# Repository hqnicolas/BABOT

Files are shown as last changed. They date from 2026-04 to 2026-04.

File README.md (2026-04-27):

# BaBot: Advanced 3-DOF Stewart- Gough Ball-Balancing Robot

An autonomous high-precision ball-balancing instrument predicated on a 3-DOF Stewart-Gough parallel kinematic mechanism. Powered by an ESP32-S3 microcontroller, the system integrates custom KiCad PCB hardware, a high-density 16-channel IR sensory array, and an asynchronous WebSocket-driven control interface for real-time telemetry and PID optimization.

This project represents a modern realization of parallel robotics, bridging classical control theory with contemporary high-frequency embedded systems.

https://github.com/user-attachments/assets/6e9986bd-6b06-4d86-9c46-4f5fcbdaf4ec

**License:** [Creative Commons Attribution-NonCommercial 4.0 International](LICENSE)

---

## Quick Start

### Prerequisites

- Arduino IDE with ESP32 board support
- ESP32-S3 development board or compatible target
- Physical BaBot hardware assembled

### Compilation

1. Open `firmware/firmware.ino` in Arduino IDE.
2. Select **ESP32S3 Dev Module** or your specific ESP32-S3 variant.
3. Click **Compile**.

On Windows, the helper script is also available:

```powershell
.\scripts\compile.ps1
```

### First Boot

1. Power on the robot.
2. Wait for the ESP32-S3 Wi-Fi access point.
3. Connect to Wi-Fi network `12345678` using password `12345678`.
4. Open `http://192.168.4.1/`.
5. The live control dashboard loads with telemetry and runtime controls.

---

## Features

- **Precision 3-DOF Stewart Platform** - A high-rigidity parallel kinematic architecture utilizing three independent actuator branches for precise control of posture and stability.
- **Async Web Control Ecosystem** - Low-latency dual-core dashboard featuring real-time state visualization, ball trajectory overlays, and holistic system diagnostics via WebSockets.
- **High-Density IR Sensory Matrix** - 16-channel infrared detection grid employing signed signal processing and individual multiplexer channel compensation.
- **Synchronized 30Hz Control Loop** - Deterministic real-time control orchestrated by a dedicated FreeRTOS sensor task, ensuring minimal phase lag between optical acquisition and mechanical actuation.
- **Machine Learning PID Autotune** - Autonomous gain discovery utilizing a Multi-Stage CMA-ES (Covariance Matrix Adaptation Evolution Strategy) search algorithm for noise-tolerant feedback optimization.
- **Mathematical Kinematics Solver** - Native C++ real-time implementation of Stewart-Gough inverse kinematics, eliminating the need for legacy lookup tables or offline pre-computation.
- **Robust Fail-Safe Architecture** - Multi-stage subsystem health monitoring with automated recovery protocols and persistent NVS calibration storage.

---

## Firmware Modules

| Module | Purpose |
|---|---|
| `firmware.ino` | Arduino `setup()`/`loop()` orchestration, hardware object composition, and shared runtime state |
| `ButtonInput.h` | Boot-button press decoding and lightweight status LED stubs |
| `ControlLoop.h` | PID, capture impulse, motion grace, telemetry publication, and closed-loop reset helpers |
| `PidAutotune.h` | Safe relay PID autotune state machine, metrics, gain estimation, start/cancel/restore |
| `StartupManager.h` | Bench-safe startup, subsystem health, degraded-mode policy, and deferred hardware bring-up |
| `ModeHandlers.h` | ON/OFF/test/calibration/assembly/position-test mode behavior |
| `UiCommandHandler.h` | Web UI command dispatch, runtime patching, persistence commands, and MUX compensation |
| `BoardConfig.h` | Pin definitions, mux layout, timing, PID defaults, and firmware constants |
| `RuntimeState` | Shared telemetry/config state, UI command queue, status models, and NVS runtime persistence |
| `PlatformControl` | Stewart-platform inverse kinematics and servo commands |
| `IRSensorArray` | Single-mux IR reading, signed signal processing, MUX compensation, ball detection, and centroid calculation |
| `X9C104Digipot` | Digital potentiometer control for IR LED brightness tuning |
| `WebUiServer` | HTTP server, WebSocket telemetry, embedded Web UI, and UI command parsing |
| `DebugLogger` | Async serial logging queue flushed from the Wi-Fi task |

---

## Hardware Pinout

ESP32-S3 control pins are defined in `firmware/src/BoardConfig.h`.

| Signal | GPIO | Notes |
|---|---:|---|
| `SERVO_A` | 41 | Servo output A |
| `SERVO_B` | 2 | Servo output B |
| `SERVO_C` | 1 | Servo output C |
| `IR_LED_CONTROL` | 45 | IR illumination control |
| `BOOT_BUTTON` | 0 | Runtime app button, active-low |
| `U12_CS` | 14 | X9C104 chip select |
| `U12_INCREMENT` | 12 | X9C104 increment |
| `U12_UP/DOWN` | 13 | X9C104 direction |
| `U1_S0` | 40 | CD74HC4067 select line |
| `U1_S1` | 39 | CD74HC4067 select line |
| `U1_S2` | 48 | CD74HC4067 select line |
| `U1_S3` | 47 | CD74HC4067 select line |
| `U1_SIG` | 9 | Multiplexed ADC input |

GPIO 19 and 20 are reserved for ESP32-S3 USB D-/D+.

---

## Operation Modes

### OFF

Platform leveled, no active balancing.

### ON

- No ball detected: platform idles level.
- Fast ball entry or edge approach: capture impulse tilts toward center with normal ON-mode authority up to `20 deg`.
- Ball detected and slowed: velocity-scaled PID keeps the ball centered.
- Recent ball loss: firmware briefly holds the last tilt command, then levels and resets closed-loop state.

### ASSEMBLY

Manual one-servo-at-a-time diagnostic mode for validating mechanical assembly and range of motion.

### CALIBRATION

Interactive servo offset calibration. Offsets are persisted to NVS when calibration completes.

### TEST / INDIVIDUAL_TEST / POSITION_TEST

Open-loop platform diagnostics and synthetic ball-position tests for bring-up. `POSITION_TEST` injects a circular synthetic ball position and runs the normal ON controller, so it exercises the current runtime PID, capture behavior, setpoint, and tilt limits.

---

## Web Dashboard

Once connected to the Wi-Fi AP:

1. **Control Panel** - Tilt visualization, ball position overlay, and mode selector.
2. **Telemetry** - Real-time sensor readings, servo positions, PID state, and system status.
3. **PID Autotune** - Safe relay feedback with measured noise floor, Ku/Pu estimation, capture + PD validation, and small I-value tests.
4. **Configuration and runtime** - Digipot tap, ball threshold, setpoint, PID gains, Save Runtime, Load Runtime, and Reset Defaults.
5. **Tests and calibration** - Servo tests, position tests, assembly/calibration modes, and individual MUX compensation.

All changes sync bidirectionally over WebSocket.

---

## PID Autotune

The **PID Autotune** drawer uses safe relay feedback while actively trying to keep the ball on the tray.

1. It waits for a ball entry inside the safe operating radius.
2. It briefly levels the platform and measures optical/electrical jitter as a noise floor.
3. It runs relay feedback on X and Y with hysteresis greater than the measured noise.
4. It aborts an individual relay attempt if radius, velocity, or detection loss indicate risk, then recovers and waits for a new safe entry.
5. It estimates conservative `Ku`/`Pu`, calculates PD gains, and tests capture + PD.
6. It evaluates only tiny I values: `0.000`, `0.005`, `0.010`, and `0.020`.

Autotune relay tilt is limited to `15 deg`. ON mode can still use the normal `20 deg` platform authority. If relay response remains too noisy or unsafe after repeated safety aborts, autotune fails safely, levels the platform, and restores the previous runtime PID/capture settings. Successful autotune applies values in RAM only; **Save Runtime** remains the only NVS persistence step.

---

## Key Runtime Constants

| Constant | Current value | Notes |
|---|---:|---|
| `kControlIntervalUs` | `33333` | 30 Hz Nominal control periodicity |
| `kProportionalGain` | `3.4` | Optimized legacy proportional gain |
| `kIntegralGain` | `0.06` | Optimized legacy integral gain |
| `kDerivativeGain` | `12.0` | Optimized legacy derivative gain |
| `kPlateHeightMm` | `115.0` | Design vertical height (Nominal) |
| `kMaxPlateTiltDeg` | `15.0` | Symmetrical mechanical safety authority |
| `kBallThreshold` | `30.0` | Signed IR detection floor |

---

## Bring-Up Checklist

- [ ] Compile firmware without errors.
- [ ] Flash to ESP32-S3 via USB.
- [ ] Connect to the `12345678` Wi-Fi AP and open `http://192.168.4.1/`.
- [ ] Confirm subsystems report ready or clear degraded-state messages.
- [ ] Test `ASSEMBLY` and `CALIBRATION` modes before balancing.
- [ ] Run individual MUX compensation after sensor or lighting changes.
- [ ] Tune digipot tap and ball threshold on real hardware.
- [ ] Test ON mode with slow and moderate ball entries.
- [ ] Run PID Autotune with safe ball entries and verify noise floor, relay crossings, Ku/Pu, confidence, and estimated P/D before saving runtime values.

---

## Third-Party Libraries

Vendored libraries live in `firmware/src/third_party/`:

- ArduinoJson - JSON serialization for web communication under `firmware/src/third_party/ArduinoJson/src`
- Servo - ESP32 servo PWM output
- WebSockets - Bidirectional WebSocket communication
- CD74HC4067 - 16-channel multiplexer control

For versions, upstream sources, and licenses, see [docs/third-party-sources.md](docs/third-party-sources.md).

---

## Documentation

| Document | Content |
|---|---|
| Document | Content |
|---|---|
| [docs/kinematics-theory.md](docs/kinematics-theory.md) | **Maturity Thesis**: Stewart-Gough derivation and system geometry |
| [docs/code-reference.md](docs/code-reference.md) | Firmware architecture, CMA-ES Autotune model, and module responsibilities |
| [docs/hardware-guide.md](docs/hardware-guide.md) | Mechanical assembly and PCB asset organization |
| [docs/autotune-tutorial.md](docs/autotune-tutorial.md) | Procedural guide for autonomous PID optimization |

---

## Safety Notes

- The robot starts in `OFF` mode on power-up.
- Always test on a stable, non-slip surface.
- Keep hands clear of linkages while servos are active.
- Do not use PID Autotune on a partially assembled or mechanically loose platform.
- If autotune reports relay response too noisy or unsafe, improve sensing/mechanics before applying gains.

---

## Contact & Support

https://www.ba-bot.com
https://www.ba-bot.com/manual/

#  License
This project is licensed under the Creative Commons Attribution-NonCommercial 4.0 International License.

#  Contact
For inquiries or support, please contact: info@ba-bot.com

---
# BABOT

The open-source ball-balancing robot you build, program, and bring to life.

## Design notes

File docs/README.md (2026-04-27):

# BaBot - 3-DOF Ball-Balancing Robot

BaBot is a ball-balancing robot built on a 3-DOF Stewart platform. This repository targets the ESP32-S3 hardware revision and is arranged so the firmware compiles directly in Arduino IDE by default.

## Arduino IDE Setup

1. Install Arduino IDE and the `esp32:esp32` board platform.
2. Open the sketch folder [`../firmware/`](../firmware/).
3. Open [`../firmware/firmware.ino`](../firmware/firmware.ino).
4. Select the appropriate ESP32-S3 board target.
5. Compile directly in the IDE.

## Optional Arduino CLI

The CLI remains available as a convenience path, but it is no longer the primary workflow.

```powershell
.\scripts\compile.ps1
```

The helper script is the recommended CLI path because it injects the include roots for the integrated third-party source tree.

You can also compile the sketch directly without the helper script if you pass the same flags:

```powershell
arduino-cli compile --fqbn esp32:esp32:esp32s3 --build-property "build.extra_flags=-I<repo>\\firmware\\src -I<repo>\\firmware\\src\\third_party\\ArduinoJson\\src -I<repo>\\firmware\\src\\third_party\\CD74HC4067\\src -I<repo>\\firmware\\src\\third_party\\Servo\\src -I<repo>\\firmware\\src\\third_party\\WebSockets\\src" .\firmware
```

## Firmware Structure

- [`../firmware/firmware.ino`](../firmware/firmware.ino) keeps the Arduino `setup()` and `loop()` entrypoints plus high-level hardware composition.
- [`../firmware/src/`](../firmware/src/) contains project modules for button input, control loop, PID autotune, startup, mode handlers, UI command handling, drivers, and shared runtime state.
- [`../firmware/src/third_party/`](../firmware/src/third_party/) contains vendored third-party Arduino dependencies used by the default sketch build.
- [`../scripts/`](../scripts/) contains optional helper scripts for compile and dependency refresh.
- [`../hardware/`](../hardware/) contains board CAD, fabrication exports, enclosure assets, and hardware reference material.

## Hardware Revision

The default hardware documented in this repository is the newer main-board revision with a single `74HC4067` mux (`U1`) feeding a `4x4` sensor grid with `16` total sensors.

| Signal | GPIO | Notes |
|---|---:|---|
| `SERVO_A` | `41` | Servo output A |
| `SERVO_B` | `2` | Servo output B |
| `SERVO_C` | `1` | Servo output C |
| `U1_S0` | `40` | Remaining mux select line |
| `U1_S1` | `39` | Remaining mux select line |
| `U1_S2` | `48` | Remaining mux select line |
| `U1_S3` | `47` | Remaining mux select line |
| `U1_SIG` | `9` | Remaining mux ADC signal |
| `U12_INCREMENT` | `12` | X9C104 increment |
| `U12_UP/DOWN` | `13` | X9C104 direction |
| `U12_CS` | `14` | X9C104 chip select |
| `IR_LED_CONTROL` | `45` | IR illumination control |

The firmware pin map in [`../firmware/src/BoardConfig.h`](../firmware/src/BoardConfig.h) now matches this single-mux hardware revision.

## Third-Party Sources

- The required third-party Arduino dependencies live under [`../firmware/src/third_party/`](../firmware/src/third_party/).
- To refresh them from Arduino Library Manager, run `.\scripts\vendor-libraries.ps1`.
- Pinned versions, upstream homes, and retained licenses are tracked in [`third-party-sources.md`](third-party-sources.md).

## Runtime Notes

- The active hardware uses a single `U1` mux bank across `16` sensor positions.
- The sensor grid is `1.8x` larger than the legacy board, so the firmware now scales the mirrored legacy centroid output to preserve the old control logic on the new mechanics.
- The Boot button on GPIO0 is used as the runtime app button with `INPUT_PULLUP`. The firmware ignores boot-held state until the button has first been released after startup, so Boot+Reset still remains available for download mode entry.

- The default digital potentiometer tap is `5`, and the ESP32 12-bit `kBallThreshold` baseline is `60.0`. Both are expected to need hardware recalibration.
- The main loop uses fast-path button handling, a 30 Hz control path, signed IR readings, transient capture impulses for fast ball entries, velocity-scaled PID stabilization, and a persisted servo calibration routine.
- The Web UI **PID Autotune** routine uses safe relay feedback with capture active. It measures the noise floor, uses hysteresis to reject optical/electrical jitter, estimates conservative Ku/Pu-based PD gains, and tests small I values only after capture/PD succeeds.
- The firmware starts a Wi-Fi access point with SSID `12345678` and password `12345678`, serves a live web control page over HTTP, and streams telemetry through WebSocket from a task pinned to core `0`.
- Debug output uses the regular ESP32 serial monitor path. Log records are queued from the control path and flushed from the Wi-Fi/web task so serial printing does not run inline in `loop()`.
- Startup is now split into a safe boot plus deferred hardware stages. The board brings up serial, shared state, Wi-Fi, and the web page first, then initializes actuator, digipot, and IR subsystems one at a time.
- If the previous boot reset during actuator or digipot startup, the next boot automatically skips that risky stage, enables a dummy backend where needed, and reports the degraded state on both serial and the web page instead of looping on reset.

## Web UI Access

1. Power the robot and wait for the ESP32-S3 access point to start.
2. Join the Wi-Fi network named `12345678` using password `12345678`.
3. Open a browser and go to `http://192.168.4.1/`.
4. If `192.168.4.1` does not load, check the connected network details on your phone or computer and use the access point gateway/router IP shown there.
5. Once the page loads, the browser connects back to the robot over WebSocket on port `81` automatically.
6. Check the startup banner and subsystem list at the top of the control panel. On a bench boot with missing hardware, the page should still load and explicitly report any dummy or degraded subsystems.

## Bring-Up Checklist

- Compile in Arduino IDE, or with `arduino-cli compile --fqbn esp32:esp32:esp32s3 .\firmware` plus the project include flags shown above.
- Confirm the remaining `U1` mux bank returns distinct ADC values across all `16` sensor positions.
- Verify the X9C104 only moves when the target tap changes.
- Check neutral platform height, assembly mode, calibration mode, and servo limits.
- Connect to the `12345678` AP, open the hosted page, and verify live ball graphics plus bidirectional variable updates.
- On a bench test with no servos attached, confirm the page still loads, serial logs continue, and the actuator subsystem reports degraded or disabled state instead of rebooting the board.
- Re-tune the digipot default tap and ball threshold on real hardware.

## Reference Documents

- [`code-reference.md`](code-reference.md) - firmware reference for the modular ESP32-S3 codebase
- [`reference/how-it-works.pdf`](reference/how-it-works.pdf) - system theory
- [`reference/manual.pdf`](reference/manual.pdf) - assembly and usage manual
- [`hardware-guide.md`](hardware-guide.md) - hardware asset map for boards, fabrication, and enclosure files

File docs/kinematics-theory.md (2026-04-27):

# BaBot - Kinematics Theory and System Geometry

## 1. Introduction to the Stewart mechanism
The BaBot platform utilizes a 3-DOF (Degrees of Freedom) parallel manipulator based on the Stewart-Gough platform principle. This architecture provides high mechanical rigidity and precise control over the platform's posture, specifically its height ($Z$), roll ($\alpha$), and pitch ($\beta$).

Unlike serial manipulators where errors accumulate along the linkage chain, the parallel arrangement of the BaBot distributes the load and precision across three independent actuator branches (Servos A, B, and C).

## 2. Geometric Constants
The system is defined by five critical physical lengths, as extracted from the legacy robot design:

| Constant | Symbol | Value | Description |
|---|---|---|---|
| `kBaseRadiusMm` | $L$ | $85.0$ mm | Radial distance from the origin to each servo anchor point. |
| `kPlatformRadiusMm` | $R_p$ | $103.92$ mm | Radial distance from the platform center to each linkage anchor. |
| `kServoArmLengthMm` | $r$ | $70.0$ mm | Length of the primary servo horn arm. |
| `kPassiveLinkLengthMm` | $l$ | $85.0$ mm | Length of the passive linkage rod. |
| `kPlateHeightMm` | $d$ | $115.0$ mm | Nominal vertical height of the platform center at rest. |

## 3. Inverse Kinematics (IK)
The Inverse Kinematics problem for the BaBot is: *Given a desired platform height $Z$ and tilt angles $\alpha$ (roll) and $\beta$ (pitch), calculate the required angles $\theta_i$ for each servo motor.*

### 3.1. Reference Frame and Coordinate Mapping
The origin $(0,0,0)$ is located at the geometric center of the base triangle. The three servo anchors are distributed at $120^\circ$ intervals:
- **Servo A**: $210^\circ$ (or $-150^\circ$)
- **Servo B**: $90^\circ$
- **Servo C**: $-30^\circ$ (or $330^\circ$)

### 3.2. Platform Anchor Positions
For a given roll ($\alpha$) and pitch ($\beta$), we define a rotation matrix or use vector rotation to find the position of the three anchor points on the moving plate. The firmware uses a simplified geometric projection since the BaBot typically operates at small tilt angles ($<20^\circ$), but it maintains precision by calculating the absolute 3D position of each anchor relative to its respective base servo anchor.

### 3.3. The Individual Actuator Equation
For each leg, the distance between the servo rotation axis and the platform anchor must be bridged by the combination of the servo arm ($r$) and the passive link ($l$). 

We solve for the leg distance $d_{leg}$ in the vertical action plane of the servo:
$$d_{leg}^2 = \Delta X^2 + \Delta Y^2 + \Delta Z^2$$

Applying the Law of Cosines to the triangle formed by the servo arm $r$, the link $l$, and the distance $d_{leg}$:
$$\cos(\phi) = \frac{r^2 + d_{leg}^2 - l^2}{2 \cdot r \cdot d_{leg}}$$
The final servo angle $\theta$ is then derived from the combination of the geometric elevation of the leg and the internal angle $\phi$:
$$\theta = \text{atan2}(\Delta Z, \Delta X_{planar}) - \phi$$

The ESP32 processes these equations in real-time, allowing for fluid motion without the need for pre-calculated lookup tables.

## 4. Operational Limits and Clamping
Due to the physical lengths of the rods, there is a maximum theoretical height the platform can reach. For the current hardware dimensions:
- **Horizontal Reach Needed**: $\approx 19$ mm (difference between platform and base radii).
- **Max Theoretical Height**: $\approx 154$ mm (at full vertical extension).
- **Practical Default**: $115$ mm, providing a neutral servo angle of $\approx 34.3^\circ$, optimized for maximum symmetrical tilt authority.

The firmware enforces a software clamp on the tilt angles to prevent the servos from reaching "singularity" points where the linkage could flip or lock.

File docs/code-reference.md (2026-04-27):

# BaBot - Firmware Code Reference

Reference for the modular ESP32-S3 firmware in this repository.

## Control Flow

```mermaid
flowchart TD
    A["setup()"] --> B["Initialize config-dependent peripherals"]
    B --> C["Load servo offsets and home digipot"]
    C --> D{"Startup Ready?"}
    D -->|Yes| E["Start Sensor Task (Core 1)"]
    E --> F["loop() / Control Loop (Core 1)"]
    D -->|No| D
    
    subgraph SensorTask ["FREE RTOS: Sensor Task (Core 1)"]
        ST1["measure() ambient → vTaskDelay(10)"]
        ST2["measure() IR → vTaskDelay(10)"]
        ST3["Signal Semaphore: measurementReady"]
        ST1 --> ST2 --> ST3 --> ST1
    end

    subgraph MainLoop ["Arduino loop() (Core 1)"]
        L1["Button check + Mode switching + drain UI commands"]
        L2{"Semaphore: measurementReady?"}
        L2 -->|No| L1
        L2 -->|Yes| L3["Run PID / Autotune / Position Test"]
        L3 --> L4["PlatformControl.movePlatform()"]
        L4 --> L1
    end

    subgraph WebTask ["FREE RTOS: Web Task (Core 0)"]
        W1["Wi-Fi AP + HTTP Server"]
        W2["WebSocket Telemetry + UI Command Enqueue"]
        W1 <--> W2
    end
```

## Files And Responsibilities

### [`../firmware/firmware.ino`](../firmware/firmware.ino)

- Keeps Arduino `setup()` and `loop()` entrypoints, hardware object composition, and shared runtime state.
- Includes focused internal modules for button input, control loop, PID autotune, startup, mode handlers, and UI command handling.
- Orchestrates the cooperative execution between the Arduino loop and the FreeRTOS sensor measurement task.

### Internal Firmware Modules

- `ButtonInput.h` decodes Boot-button press patterns and owns lightweight status LED stubs.
- `ControlLoop.h` owns PID, capture impulse, motion grace, telemetry publication, and closed-loop reset helpers.
- `PidAutotune.h` owns safe relay PID autotune, metrics, gain estimation, and previous-gain restore.
- `StartupManager.h` owns bench-safe startup, subsystem health, degraded-mode policy, and deferred hardware initialization.
- `ModeHandlers.h` owns ON/OFF/test/calibration/assembly/position-test behavior.
- `UiCommandHandler.h` owns Web UI command dispatch, runtime patching, persistence commands, and MUX compensation.

### [`../firmware/src/BoardConfig.h`](../firmware/src/BoardConfig.h)

- Defines the `BoardPins`, `MuxPins`, and all firmware constants.
- Encodes the routed single-mux pin map, including the `GPIO45` IR LED control line, Boot button, Wi-Fi AP settings, and web-task timing.

### [`../firmware/src/RuntimeState.h`](../firmware/src/RuntimeState.h)

- Defines shared `TelemetryState`, `RuntimeConfig`, and `UiCommand` types.
- Defines the shared `SystemStatus` model used for startup phase, subsystem health, and degraded-mode reporting.
- Publishes PID autotune metrics such as baseline/best scores, candidate queue status, progress, trial counts, and per-stage gain suggestions.
- Owns the FreeRTOS queue used to move browser-originated changes onto the control core.
- Persists runtime tuning values in the `babot_ui` NVS namespace.

### [`../firmware/src/WebUiServer.h`](../firmware/src/WebUiServer.h)

- Starts a task pinned to core `0`.
- Hosts the access-point web page and `/api/state`.
- Broadcasts telemetry/config/system-health snapshots over WebSocket, enqueues parsed commands, and flushes queued serial debug output.
- Hosts the **PID Autotune** drawer and sends start/cancel/restore commands to the control loop.

### [`../firmware/src/DebugLogger.h`](../firmware/src/DebugLogger.h)

- Owns the fixed-size FreeRTOS queue used for non-blocking debug records.
- Lets the control path enqueue bring-up logs without writing directly to the serial monitor.
- Flushes queued logs from the Wi-Fi/web task so serial transport stays off the control loop.

### [`../firmware/src/IRSensorArray.h`](../firmware/src/IRSensorArray.h)

- Samples ambient and IR-lit readings across `16` channels using a dedicated FreeRTOS task.
- Uses `vTaskDelay` during IR LED settling to yield CPU time back to the main loop and network task.
- Signals the control loop via a binary semaphore once a full measurement cycle is complete.
- Applies exponential moving average smoothing to the IR delta.
- Applies persisted per-channel MUX compensation before ball detection and centroid calculation.
- Detects ball presence from `max(irSignal) - min(irSignal) >= kBallThreshold`.
- Preserves signed IR deltas so covered sensors can report below zero instead of being clamped.
- Mirrored-edge centroid calculation over the `4x4` grid so edge sensors behave like the Leonardo firmware.
- Scales the reported `centerX` / `centerY` coordinates by `1.8x` to match the larger physical sensor grid on the new hardware.
- Emits optional CSV telemetry.

### [`../firmware/src/PlatformControl.h`](../firmware/src/PlatformControl.h)

- Wraps the three `Servo` instances.
- Implementation of the Inverse Kinematics (IK) logic. For the underlying mathematical derivation, see [Kinematics Theory](kinematics-theory.md).
- Leg-to-servo ordering (`C`, `A`, `B`) inside `movePlatform()` so closed-loop motion matches the old board.
- Attaches servos with explicit pulse widths for the ESP32 PWM implementation.
- Persists per-servo calibration offsets in ESP32 NVS using `Preferences`.
- Falls back to a dummy backend when startup policy or init results disable real actuator output.

### [`../firmware/src/X9C104Digipot.h`](../firmware/src/X9C104Digipot.h)

- Replaces the previous absolute-byte digipot write path.
- Tracks the last known tap in RAM.
- Homes to zero when first used, then steps incrementally to the requested tap.
- Supports optional non-volatile store via the `persist` argument to `setTap()`.
- Can also run in a dummy mode that preserves the requested tap in software without touching GPIO.

## Startup Model

- `setup()` now performs only safe boot work first: serial, button basics, config load, shared state, and Wi-Fi/web startup.
- Riskier hardware stages then run one at a time from `loop()`: actuator backend, digipot restore, and IR sensor bring-up.
- A tiny NVS startup journal records the currently attempted risky stage. If the board resets during that stage, the next boot skips it and reports the recovery through serial and the web UI.
- `ON` mode can continue with a dummy actuator backend for bench testing, but actuator test modes are blocked unless real servo output is available.

## Key Constants

| Constant | Value | Notes |
|---|---:|---|
| `kProportionalGain` | `3.4` | Default PID proportional gain |
| `kIntegralGain` | `0.06` | Default PID integral gain |
| `kDerivativeGain` | `12.0` | Default PID derivative gain |
| `kServoArmLengthMm` | `70.0` | Primary servo horn arm length |
| `kPassiveLinkLengthMm` | `85.0` | Passive linkage rod length |
| `kBaseRadiusMm` | `85.0` | Radius to base servo mounts |
| `kPlatformRadiusMm` | `103.9` | Radius to platform anchors |
| `kPlateHeightMm` | `115.0` | Neutral resting height |
| `kIrAlpha` | `0.8` | IR delta smoothing |
| `kBallPositionAlpha` | `0.7` | Ball position smoothing |
| `kMaxPlateTiltDeg` | `15.0` | Safety clamp for roll/pitch |
| `kBallThreshold` | `30.0` | IR signal detection threshold |
| `kSensorCount` | `16` | 1 mux x 16 channels |
| `kPositionTestRadius` | `1.2` | Simulated path radius for `POSITION_TEST` |

## Position Test

- `POSITION_TEST` is a controller test, not a sensor-channel sweep.
- It injects a synthetic circular ball position inside the same coordinate limits used by `ON` mode.
- It then calls the normal ON controller path, so the current runtime PID, capture behavior, setpoint, ball threshold, and `kMaxPlateTiltDeg` clamp are exercised together.
- Individual MUX/channel validation belongs to the MUX compensation and sensor diagnostics flow, not `POSITION_TEST`.

## PID Autotune Model

- Autotune utilizes a **Multi-Stage CMA-ES (Covariance Matrix Adaptation Evolution Strategy)** optimizer, a machine learning method designed for noise-tolerant search in high-dimensional feedback loops.
- It operates in three distinct phases:
    1. **Baseline**: Establishes a performance floor using current gains.
    2. **CMA-ES Evolution**: Samples a population of 6 candidates from a dynamic Gaussian distribution. It adaptively learns from each evaluation, shifting the search mean and adjusting the covariance matrix to stretch along the most promising gain directions.
    3. **Tune I**: Fine-tunes the Integral gain once the P/D stabilization is optimized, minimizing steady-state error.
- **Scoring Function**:
    - Each candidate is graded via a composite cost function: `Score = (Avg Radius * 150) + (Avg Speed * 120) + (Peak Speed * 50) + (Time * 0.04)`.
    - **Edge Penalty**: If the ball is "captured" but remains against the outer fence (Avg Radius > 0.8), a 300-point penalty is applied.
- **Robustness**: 
    - **Trial Averaging**: Each candidate is tested over `kPidAutotuneTrialsPerCandidate = 3` trials.
    - **Safety & Early Cancel**: The autotuner allows the full platform tilt (10.0°). If the user cancels the session early, the **best gains found so far** are automatically applied to the active controller.
- Autotune applies the resulting values in RAM only. `Save Runtime` remains the only NVS persistence step.

## Third-Party Layout

- Vendored dependencies live under [`../firmware/src/third_party/`](../firmware/src/third_party/), including ArduinoJson under `ArduinoJson/src`.
- Arduino IDE is the primary workflow. The helper compile script exists for CLI convenience and injects the include roots needed for the vendored source layout.

## Validation Expectations

- The baseline firmware should compile directly with:

```powershell
.\scripts\compile.ps1
```

- The helper script injects the include roots needed by the integrated `src/third_party` source tree:

```powershell
.\scripts\compile.ps1
```

## Hardware Caveats

- `kBallThreshold = 60.0` and `kDefaultDigipotTap = 5` are current bring-up values and still need hardware validation.
- Bench validation is still required for servo limits, sensor orientation, threshold tuning, and digipot calibration.

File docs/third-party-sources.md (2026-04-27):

# Third-Party Sources

This repository vendors the build-relevant portions of its third-party Arduino dependencies under `firmware/src/third_party/`.

| Dependency | Version | Upstream | Retained license files |
|---|---|---|---|
| Servo | current vendored copy | https://github.com/arduino-libraries/Servo | docs/ + examples/ included upstream |
| CD74HC4067 | 1.0.2 | https://github.com/waspinator/CD74HC4067 | LICENSE |
| WebSockets | 2.7.2 | https://github.com/Links2004/arduinoWebSockets | LICENSE |
| Async TCP | 3.3.2 | https://github.com/me-no-dev/asynctcp | LICENSE |
| ESP Async WebServer | 3.6.0 | https://github.com/me-no-dev/espasyncwebserver | LICENSE |
| ArduinoJson | 7.4.3 | https://github.com/bblanchon/ArduinoJson | LICENSE.txt (`firmware/src/third_party/ArduinoJson/src`) |

Refresh with `.\scripts\vendor-libraries.ps1`, then verify with `arduino-cli compile --fqbn esp32:esp32:esp32s3 .\firmware` or `.\scripts\compile.ps1`.

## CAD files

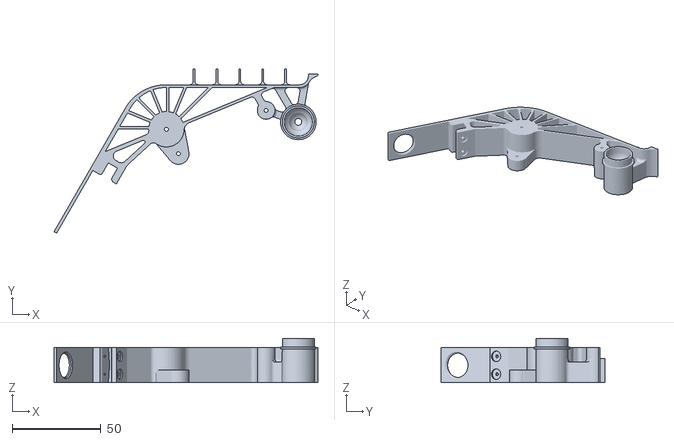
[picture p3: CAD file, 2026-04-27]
hardware/enclosure/interieur3Print1time.stl
148.6 x 92.5 x 25.0

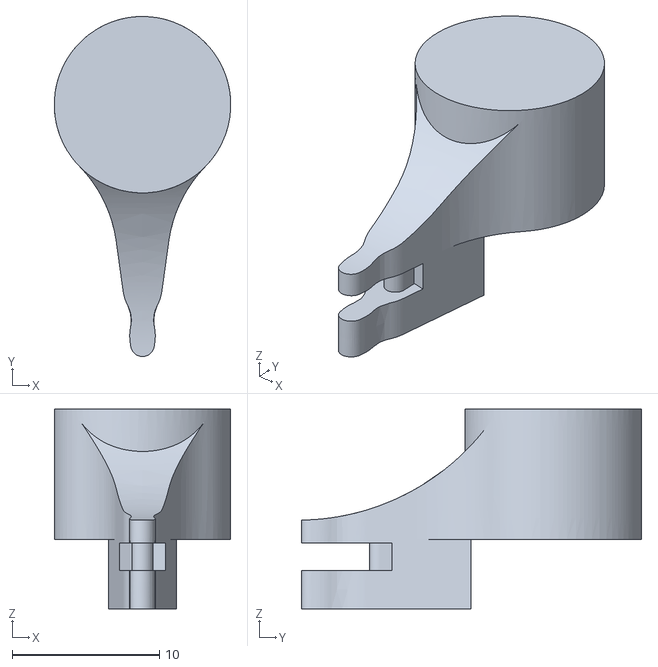
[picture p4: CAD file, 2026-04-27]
hardware/enclosure/3X_holder.stl
12.0 x 23.1 x 13.6

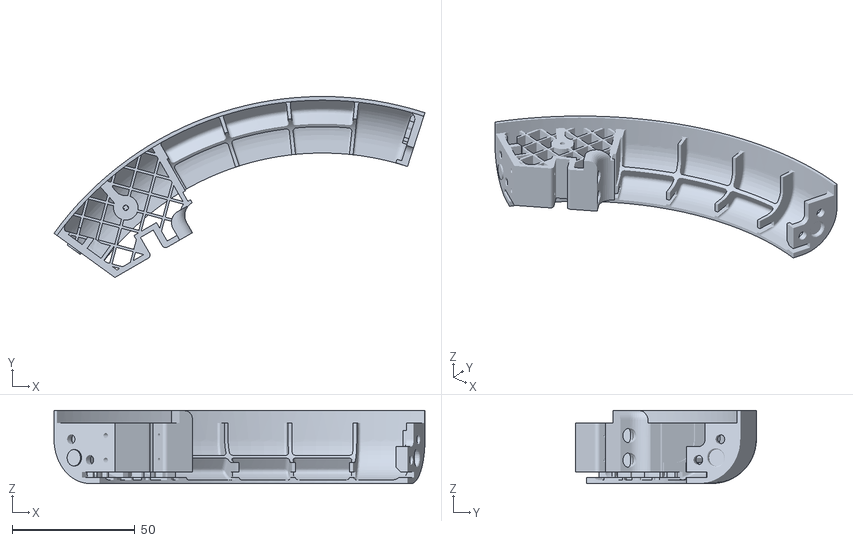
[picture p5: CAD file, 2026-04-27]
hardware/enclosure/contour1Print1time..stl
150.9 x 73.6 x 29.7

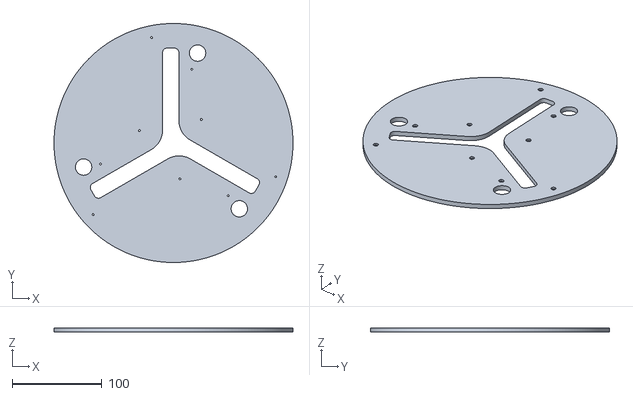
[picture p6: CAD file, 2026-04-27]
hardware/enclosure/superieur.stl
266.9 x 266.9 x 5.00

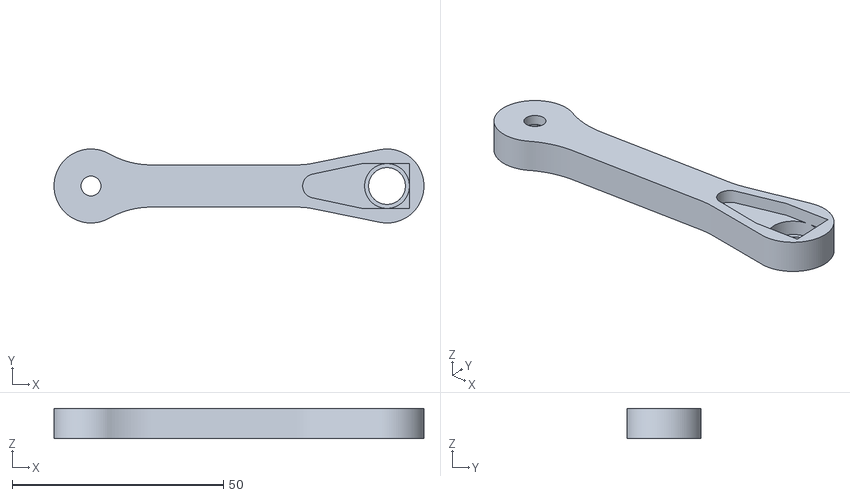
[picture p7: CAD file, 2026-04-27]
hardware/enclosure/arm1print_this_file_3_times.stl
87.5 x 17.5 x 7.20

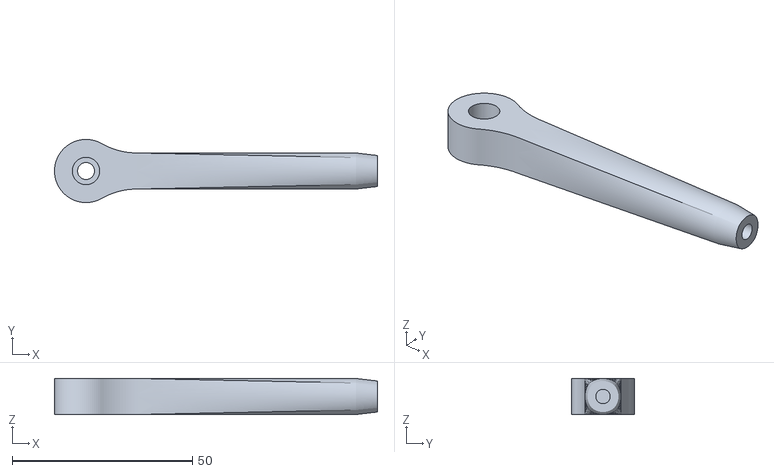
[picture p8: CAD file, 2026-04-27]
hardware/enclosure/arm2print_this_file_3_times.stl
89.5 x 17.5 x 10.0

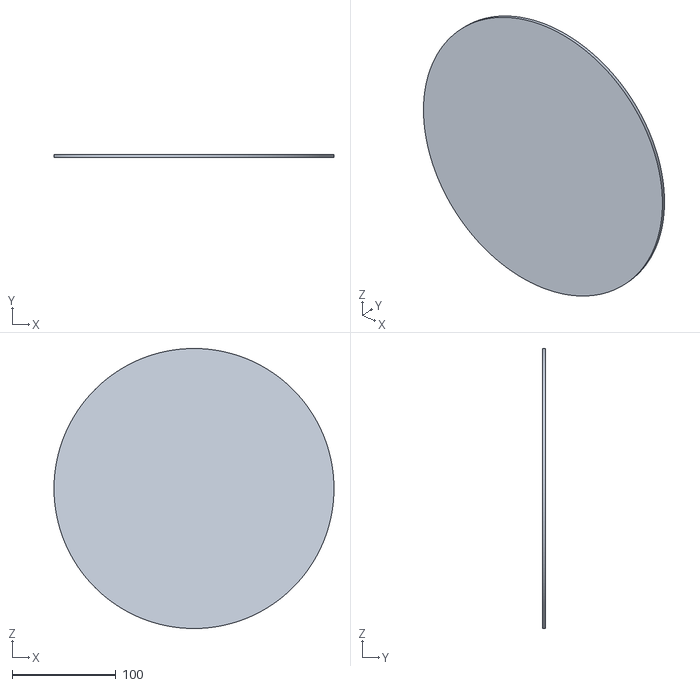
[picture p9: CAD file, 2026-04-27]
hardware/enclosure/plateau.stl
270.0 x 3.00 x 270.0

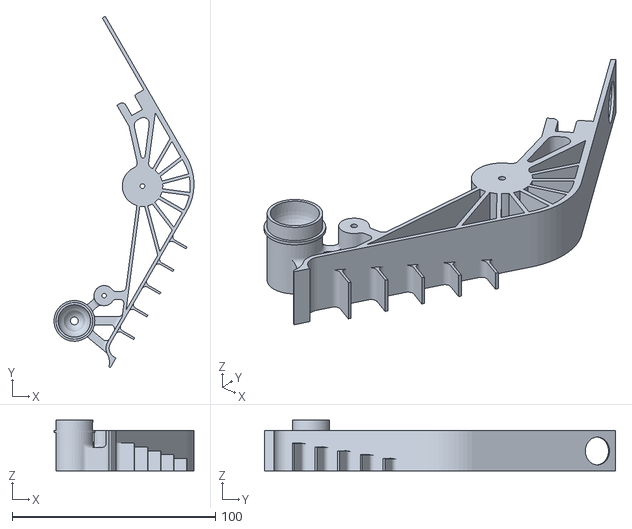
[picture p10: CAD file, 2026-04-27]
hardware/enclosure/interieurPrint1time.stl
68.9 x 173.0 x 25.0

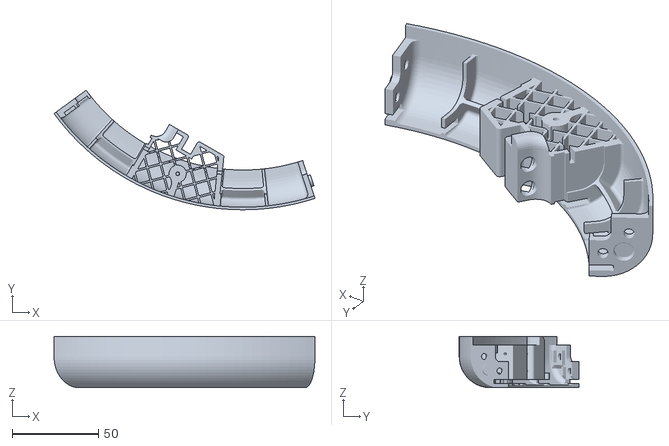
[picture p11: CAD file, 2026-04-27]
hardware/enclosure/contour2Print1time..stl
150.9 x 69.2 x 29.7

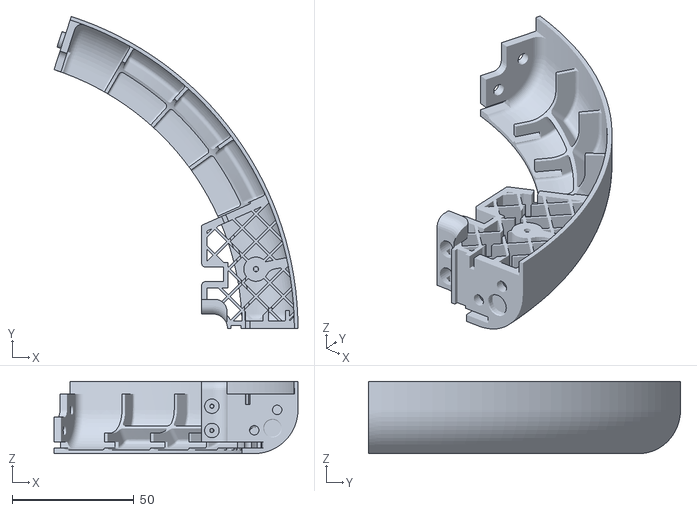
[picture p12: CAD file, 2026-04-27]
hardware/enclosure/contour4Print1time..stl
100.4 x 128.4 x 29.7

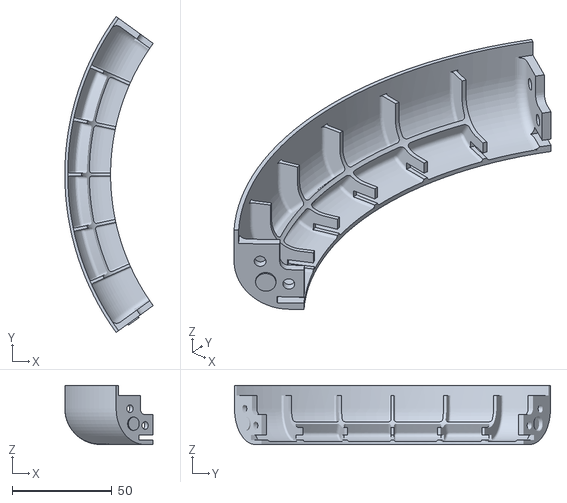
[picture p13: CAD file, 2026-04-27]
hardware/enclosure/contour5Print1time.stl
44.4 x 158.7 x 29.7

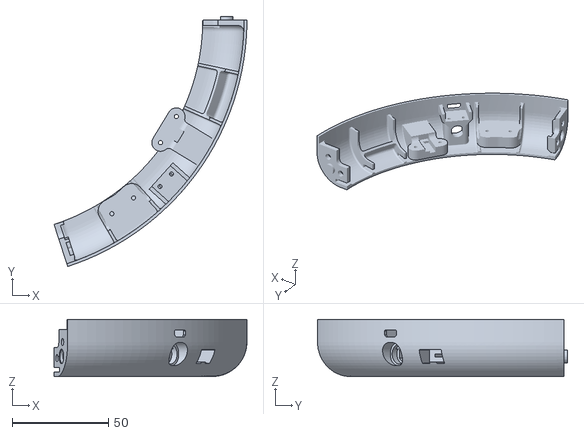
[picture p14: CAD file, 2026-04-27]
hardware/enclosure/contour3Print1time..stl
100.4 x 130.1 x 29.7

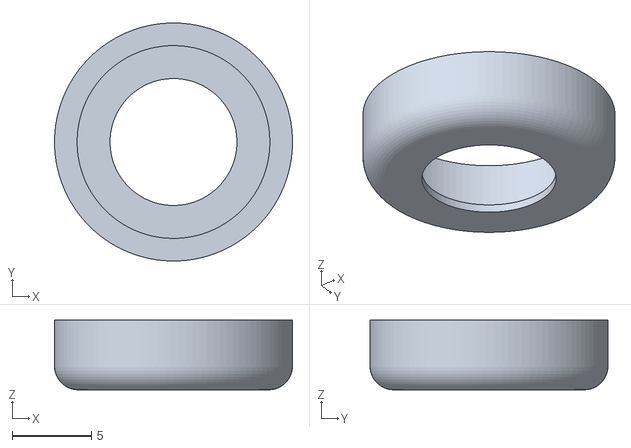
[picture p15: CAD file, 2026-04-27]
hardware/enclosure/print3times.stl
15.0 x 15.0 x 4.39

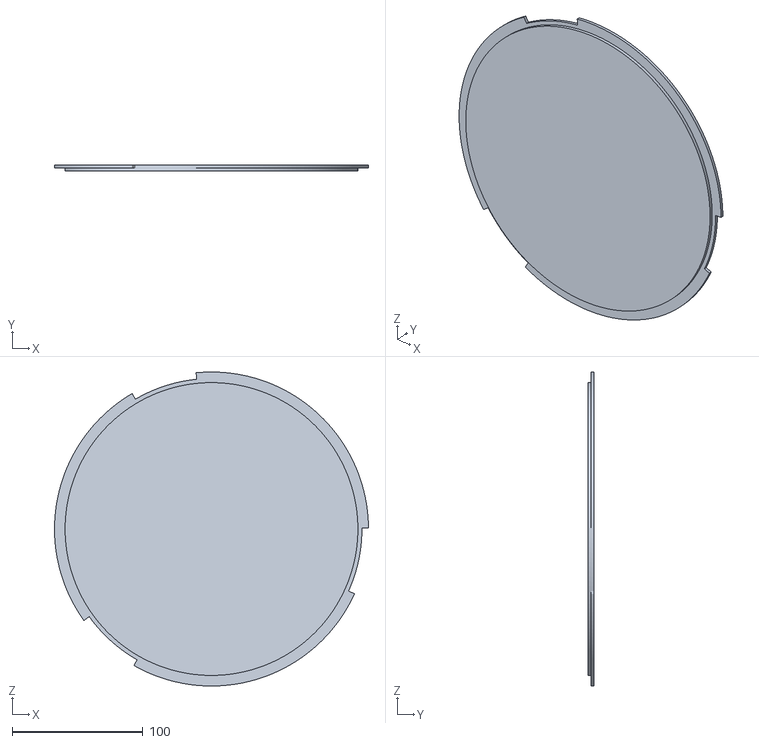
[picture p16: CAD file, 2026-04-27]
hardware/enclosure/inferieur.stl
240.0 x 4.70 x 240.0

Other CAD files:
hardware/enclosure/interieur2Print1time.stl
hardware/enclosure/supportspaced.stl

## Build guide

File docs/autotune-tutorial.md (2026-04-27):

# Tutorial: Testing the BABOT Multi-Stage PID Autotuner

This guide explains how to verify the performance and stability of the BABOT Hill Climbing autotuner.

## Prerequisites
1. **Physical Setup**: Ensure the platform is level and the servos are energized.
2. **Web UI Access**: Navigate to the BABOT Web UI in your browser.
3. **Ball on Standby**: Have the balancing ball ready to place on the plate.

---

## Step 1: Baseline Verification
The autotuner starts by measuring your "current" gains to establish a reference point.

1. Open the **PID Autotune** drawer in the Web UI.
2. Click **Start Autotune**.
3. **Action**: Place the ball on the plate when the status shows "Waiting for ball entry".
4. **Observation**: The system will run 3 trials. After completion, notice the **Baseline Score**. This is your target to beat.

## Step 2: Monitoring the Evolution Phase
The system will now enter **Evolving (CMA-ES)** mode. This is the machine learning phase where BABOT learns the physics of your plate.

1. **Trial Flow**: 
   - The system samples a "population" of 6 candidates per generation.
   - You will see the **Generation** counter (0, 1, 2...).
   - Watch the **Step Size (σ)**. As the system gains confidence in a specific region of PID space, σ will decrease.
2. **Telemetry Check**: 
   - The system automatically shifts its search toward gain combinations that produce lower scores.
   - If a generation fails to find a better set, it will expand its search (increasing σ) to find new stable regions.

## Step 3: Integral Tuning
Once a solid P/D foundation is found, the system switches to **Tuning I**.

1. **Observation**: You will see the status change to "Tuning I".
2. **Logic**: The system is now testing small increments of Integral gain (e.g., 0.005, 0.010).
3. **Criteria**: It looks for the I-gain that reduces steady-state error without making the ball "orbit" the center slowly.

## Step 4: Applying and Saving
1. **Completion**: Once the queue is empty, the status will show **Complete**.
2. **Verification**: The best gains found are automatically applied to the active controller.
3. **Persistence**: If you are happy with the performance, click **Save Runtime** in the Config drawer to write these gains to the ESP32's permanent memory (NVS).

> [!TIP]
> **Don't wait for completion?** If you are satisfied with how the ball is balancing during a trial, you can click **Cancel** at any time. The system will automatically apply the **Best Found Gains** it has recorded so far, allowing you to stop the evolution early once you see a result you like!

---

## Troubleshooting the Test
- **"Waiting for ball entry" persists**: Check your `Ball Threshold` and `Digipot Tap`. The ball must be clearly detected for a trial to start.
- **Tuner stays on one candidate**: Ensure you are not removing the ball too early. The tuner needs 3 consistent trials to move on.
- **Ball pinned against the fence**: If a candidate just pushes the ball to the edge and holds it there, it will be heavily penalized by the **Edge Penalty** (300 points). This ensures the autotuner only considers center-balancing behavior as "Better".
- **Instability**: If the ball is shaking violently, the "Best" gains might be too high for your specific linkage. You can always click **Apply Previous Gains** to revert.

## How to "Stress Test" the Result
After autotuning, switch the mode to **POSITION_TEST**. This will inject a circular synthetic ball position. If the autotune was successful, the plate should follow the simulated circular path smoothly with minimal overshoot.

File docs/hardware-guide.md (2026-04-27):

# Hardware Guide

This repository separates hardware source files, fabrication exports, enclosure assets, and shared KiCad libraries into dedicated folders.

## Hardware Layout

- [`../hardware/boards/main-board/`](../hardware/boards/main-board/) - main-board KiCad source files
- [`../hardware/boards/led-board/`](../hardware/boards/led-board/) - LED-board KiCad source files
- [`../hardware/fabrication/main-board/`](../hardware/fabrication/main-board/) - main-board fabrication and exported reference PDFs
- [`../hardware/fabrication/led-board/`](../hardware/fabrication/led-board/) - LED-board fabrication and exported reference PDFs
- [`../hardware/enclosure/`](../hardware/enclosure/) - 3D-printable enclosure STL files and mechanical reference assets
- [`../hardware/libraries/kicad/`](../hardware/libraries/kicad/) - shared KiCad symbols and footprints
- [`../hardware/reference/tm.pdf`](../hardware/reference/tm.pdf) - additional hardware reference PDF

## Notes

- Board source CAD and fabrication exports are intentionally separated so manufacturing files do not clutter the editable design directories.
- STL filenames are preserved where they appear to be fabrication-ready outputs from the original project.
- The photo asset under `hardware/enclosure/` is kept with the STL files because it documents the printed assembly.

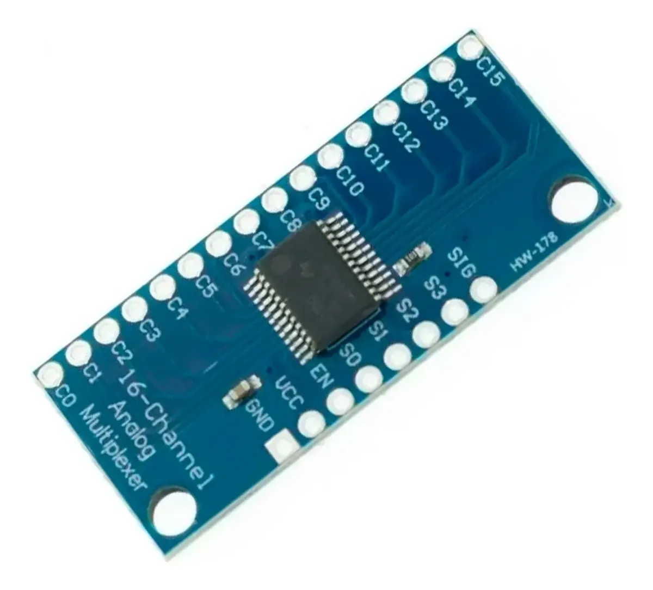
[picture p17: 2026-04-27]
hardware/fabrication/led-board/74HC4067-Board.webp

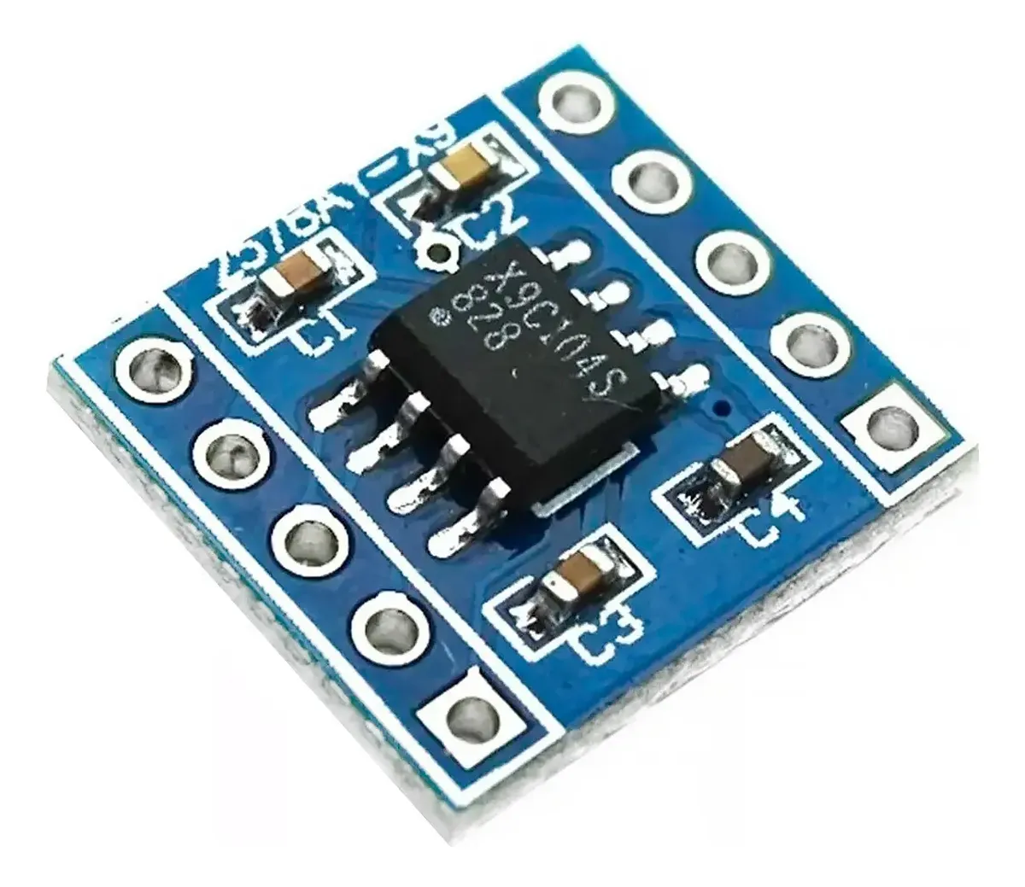
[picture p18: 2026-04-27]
hardware/fabrication/main-board/x9c104-Board.webp

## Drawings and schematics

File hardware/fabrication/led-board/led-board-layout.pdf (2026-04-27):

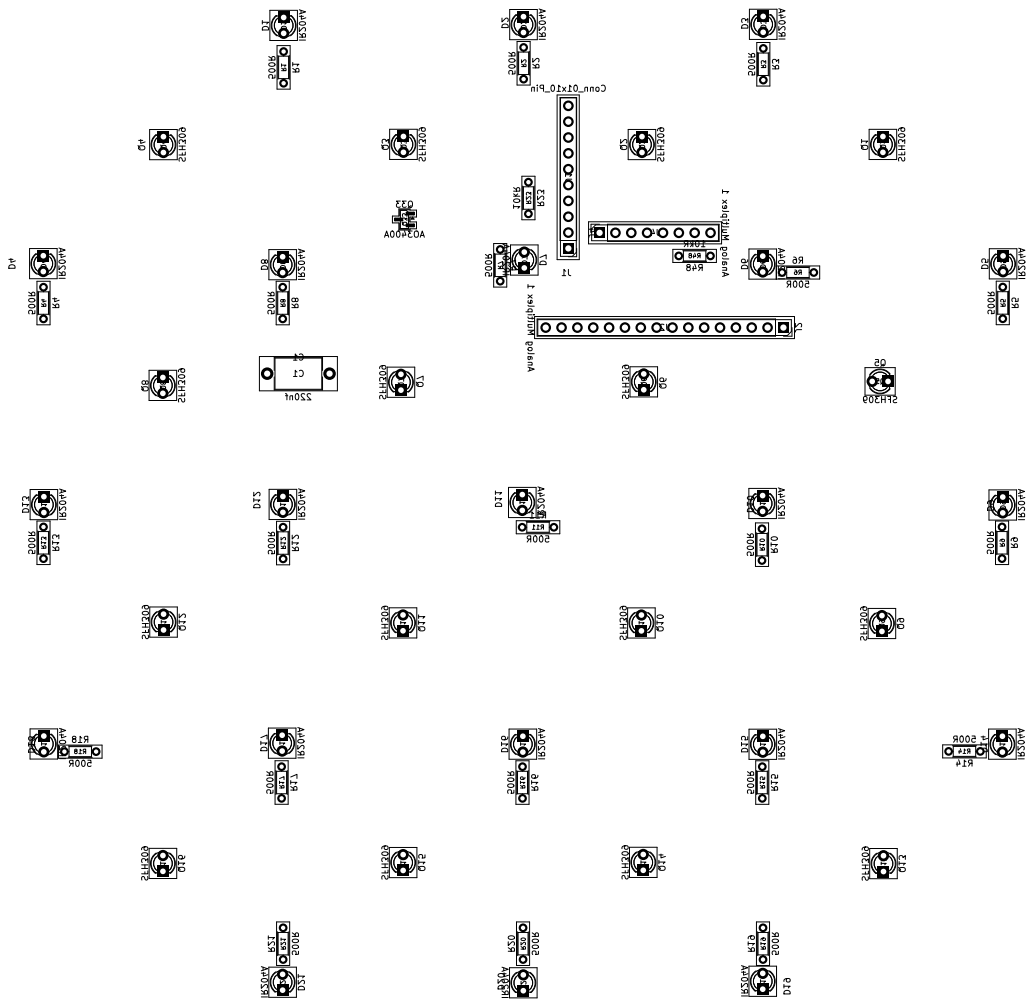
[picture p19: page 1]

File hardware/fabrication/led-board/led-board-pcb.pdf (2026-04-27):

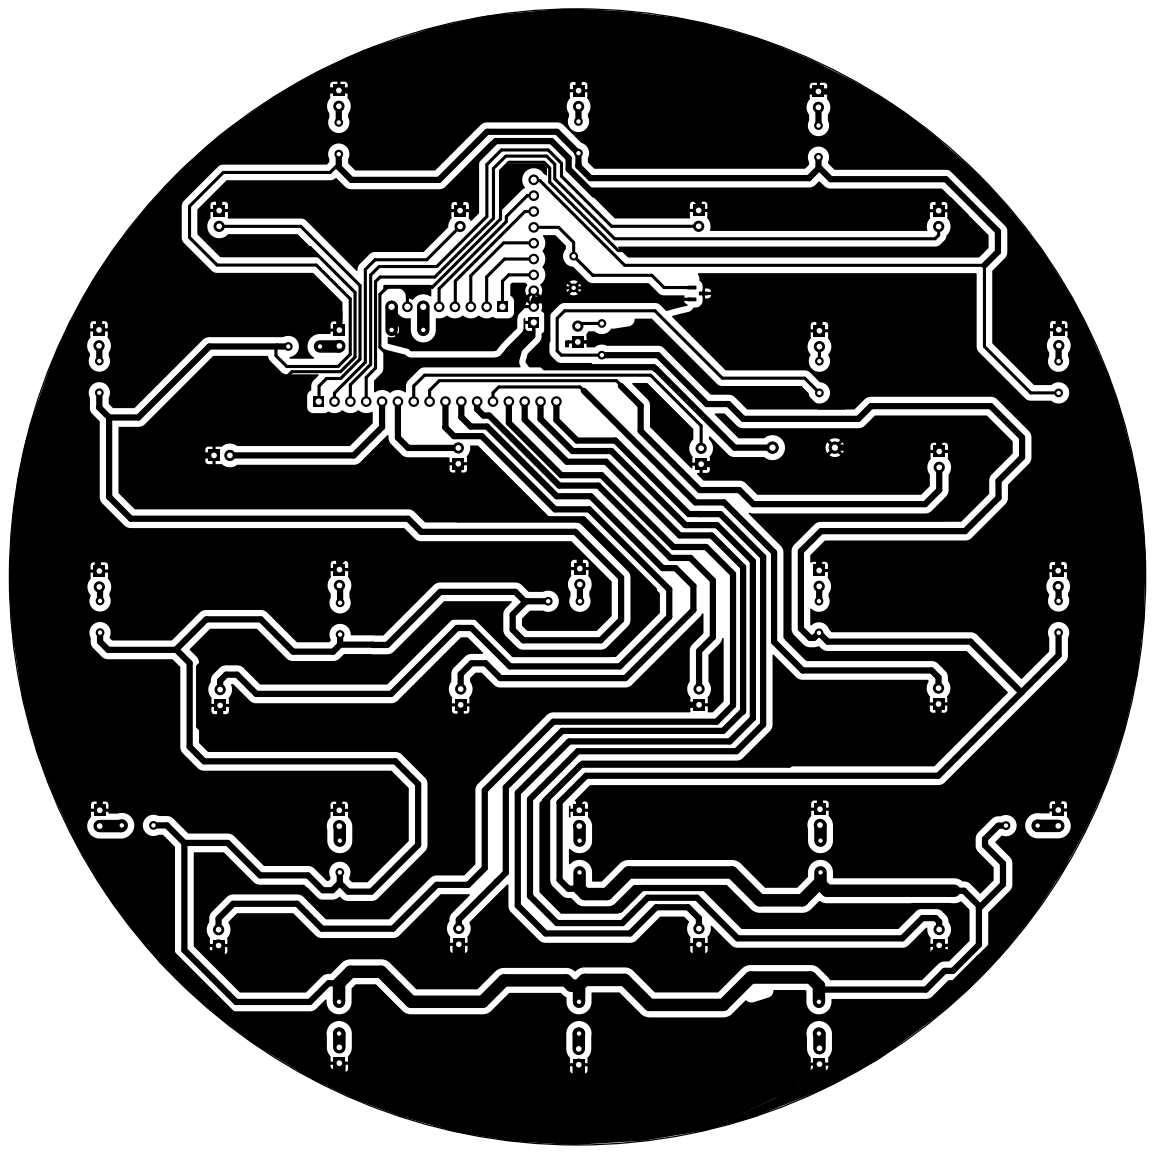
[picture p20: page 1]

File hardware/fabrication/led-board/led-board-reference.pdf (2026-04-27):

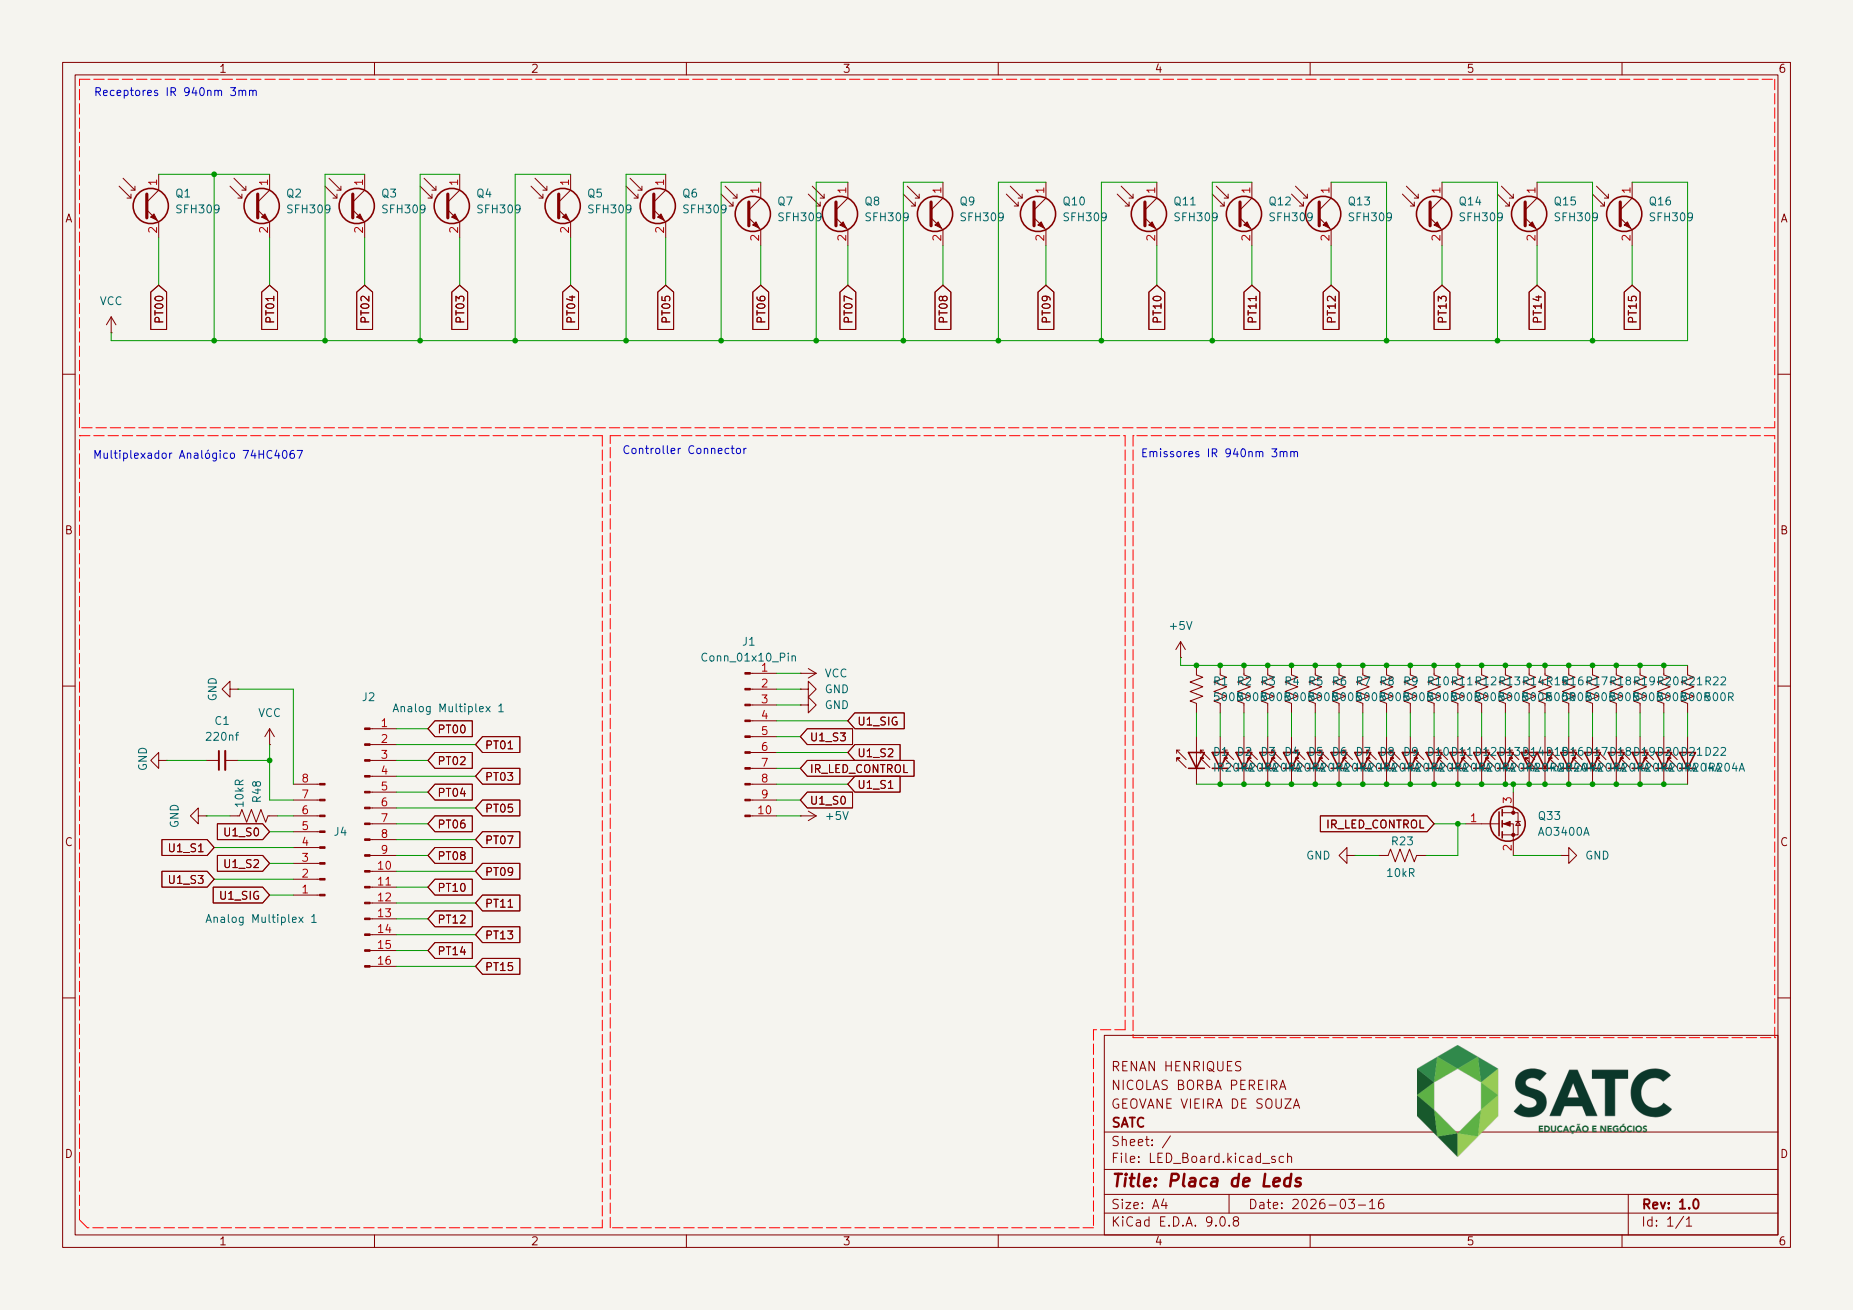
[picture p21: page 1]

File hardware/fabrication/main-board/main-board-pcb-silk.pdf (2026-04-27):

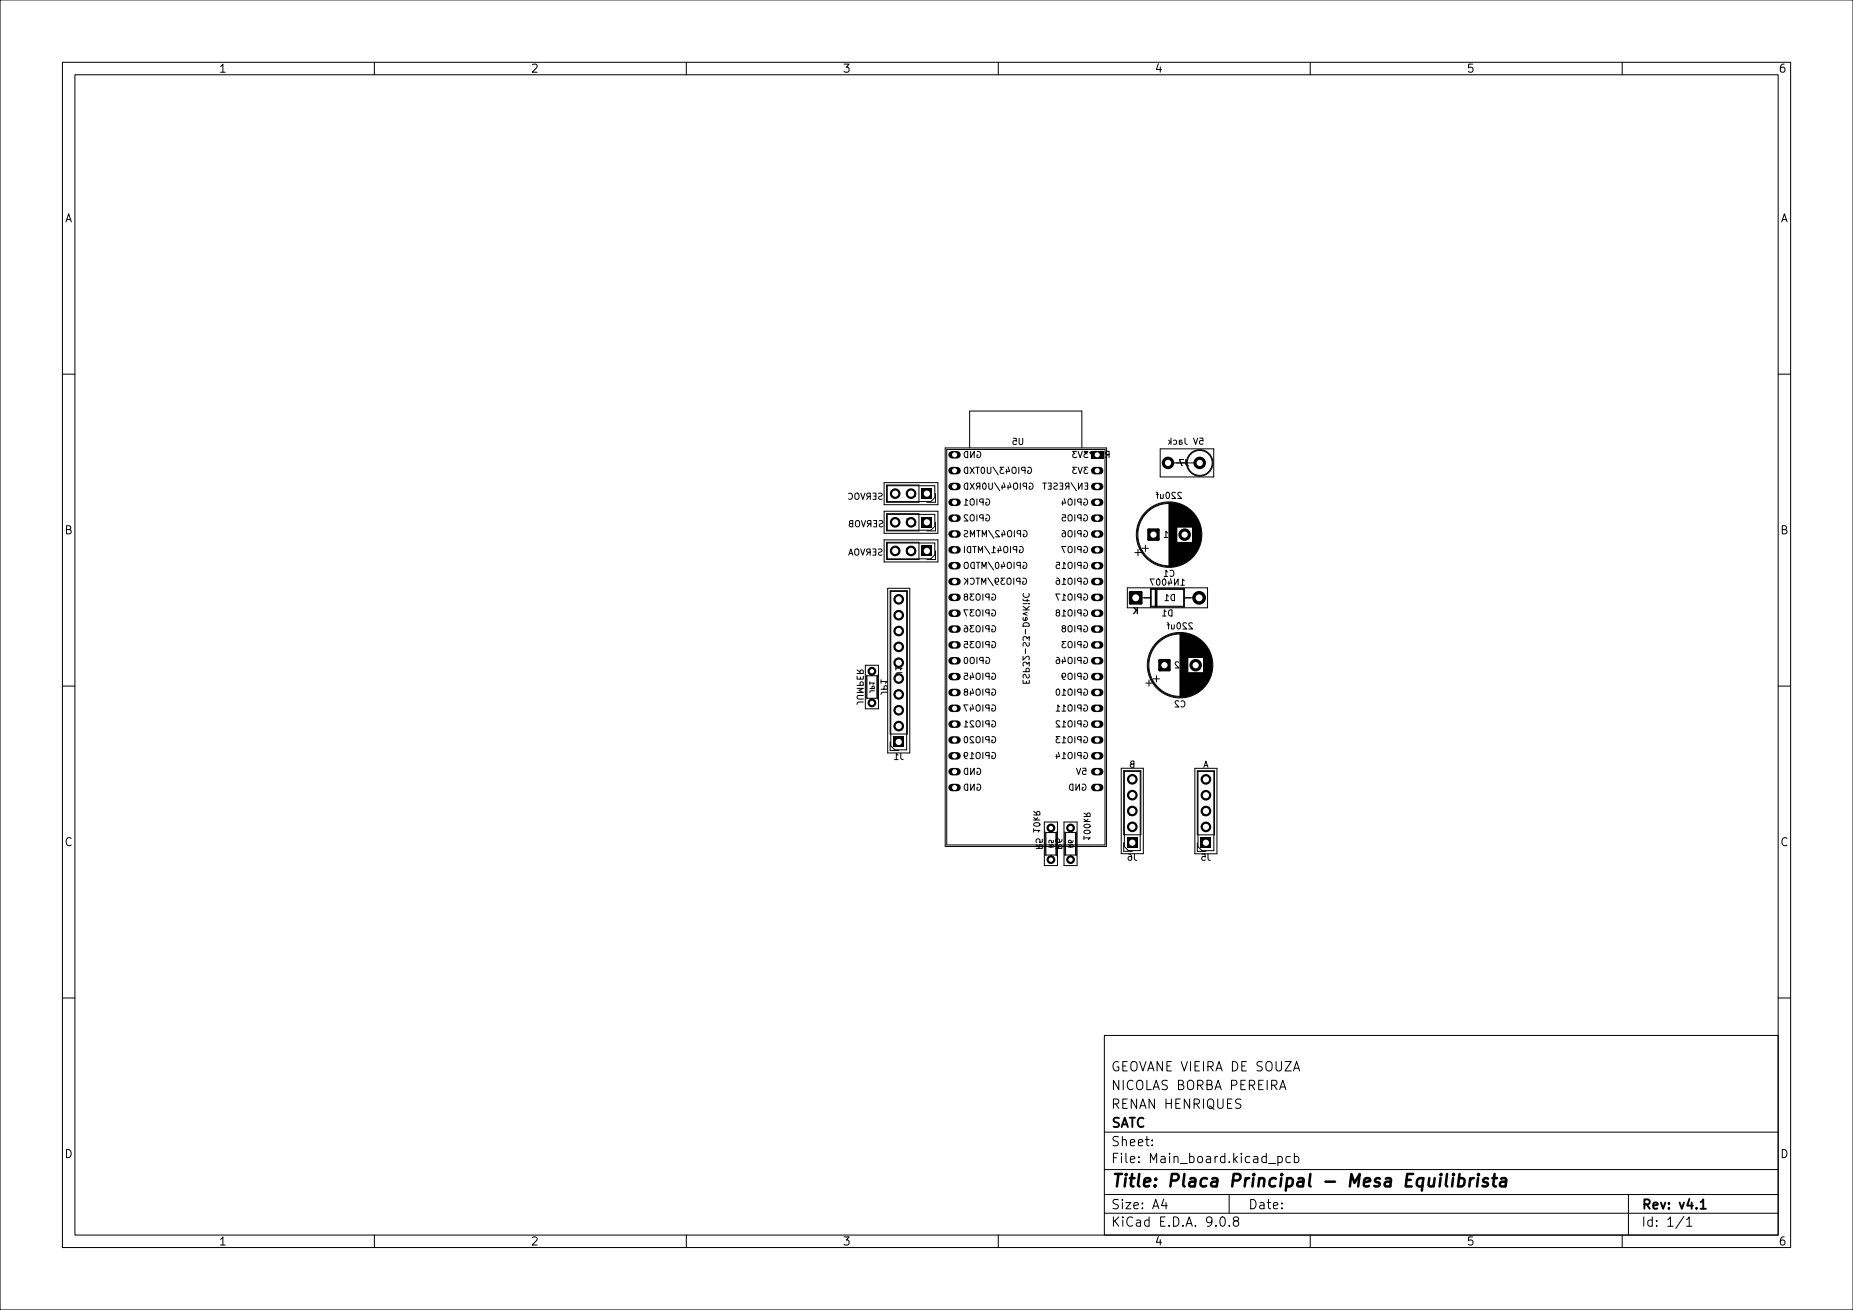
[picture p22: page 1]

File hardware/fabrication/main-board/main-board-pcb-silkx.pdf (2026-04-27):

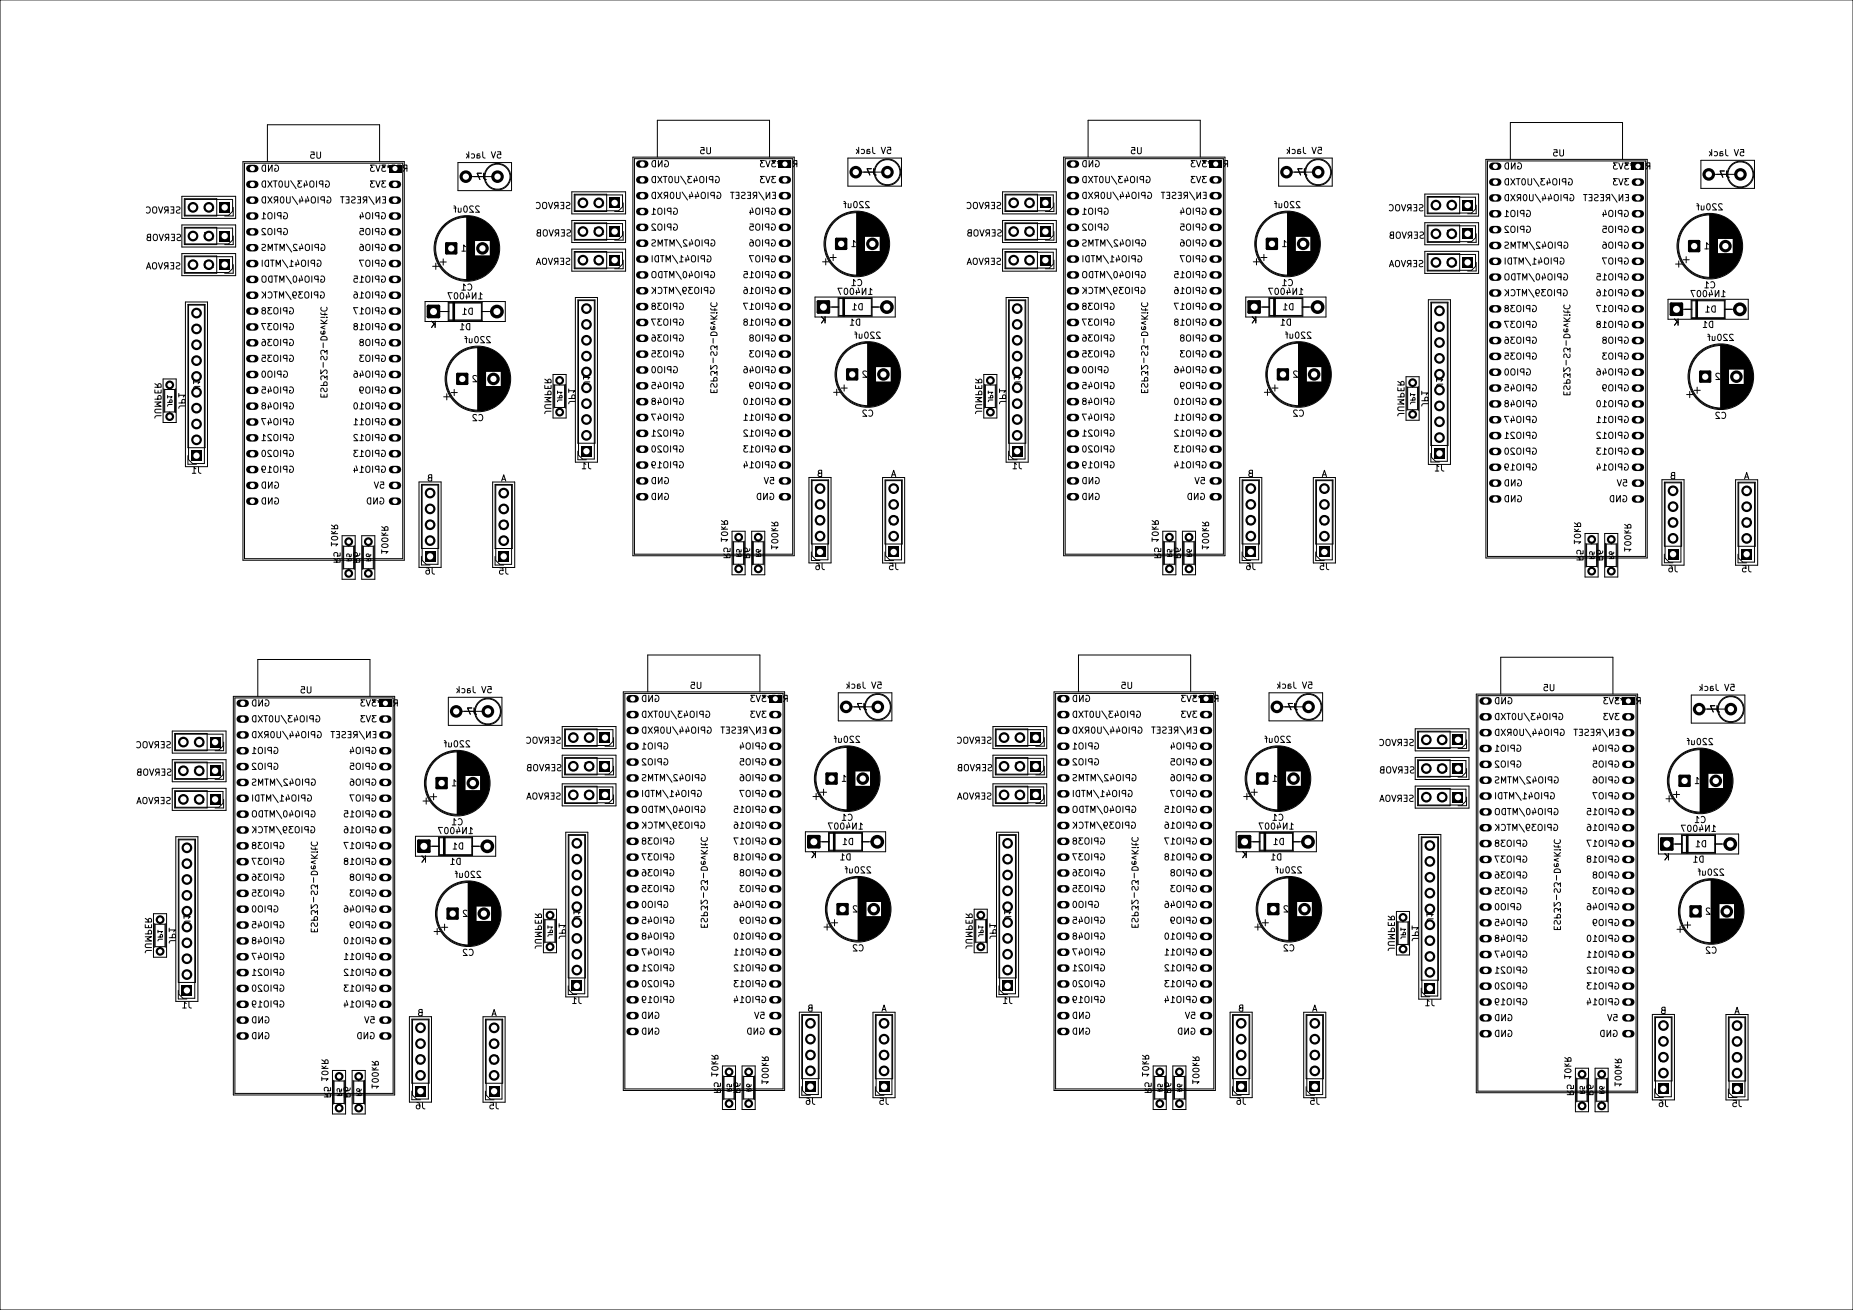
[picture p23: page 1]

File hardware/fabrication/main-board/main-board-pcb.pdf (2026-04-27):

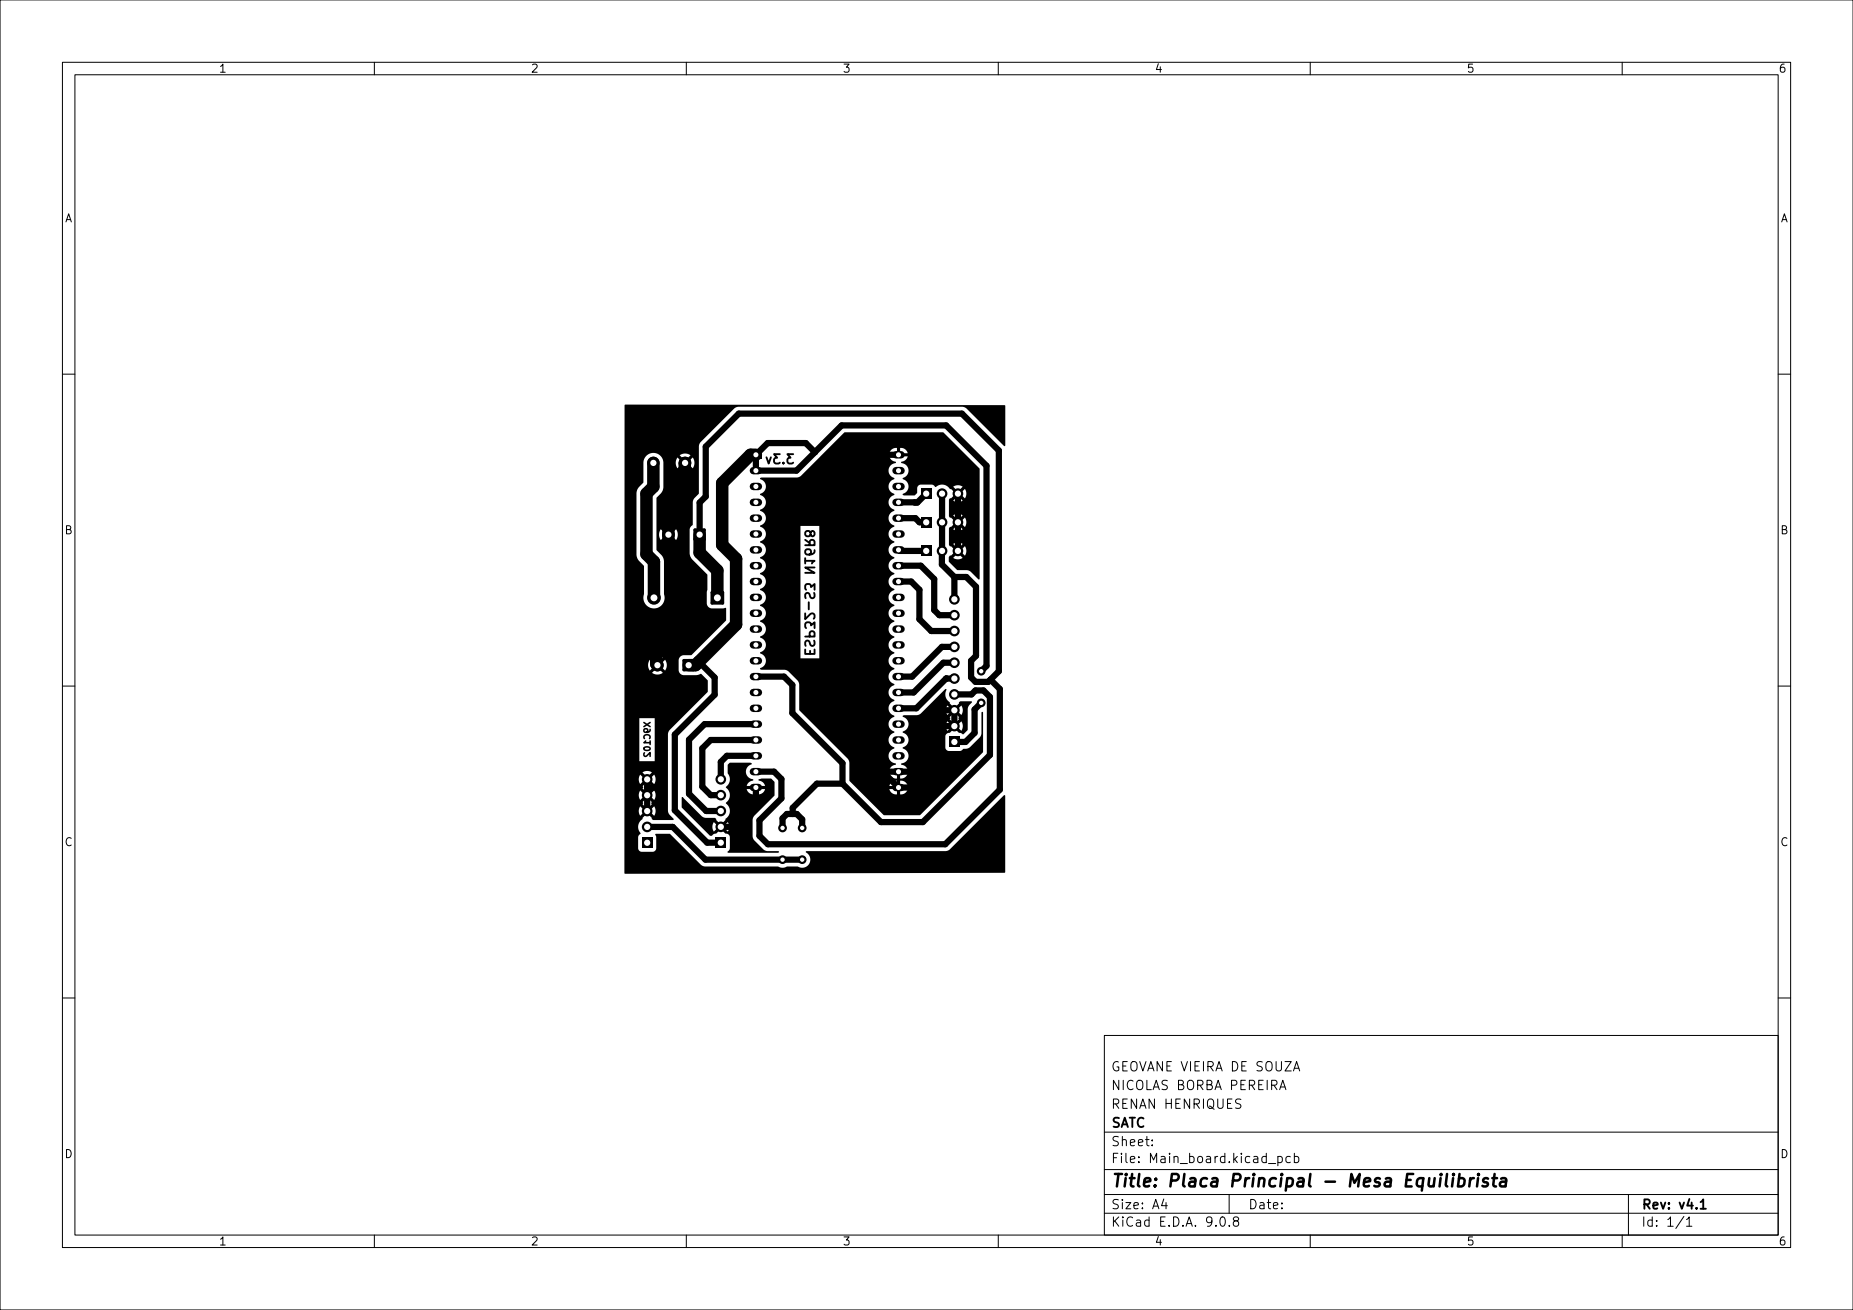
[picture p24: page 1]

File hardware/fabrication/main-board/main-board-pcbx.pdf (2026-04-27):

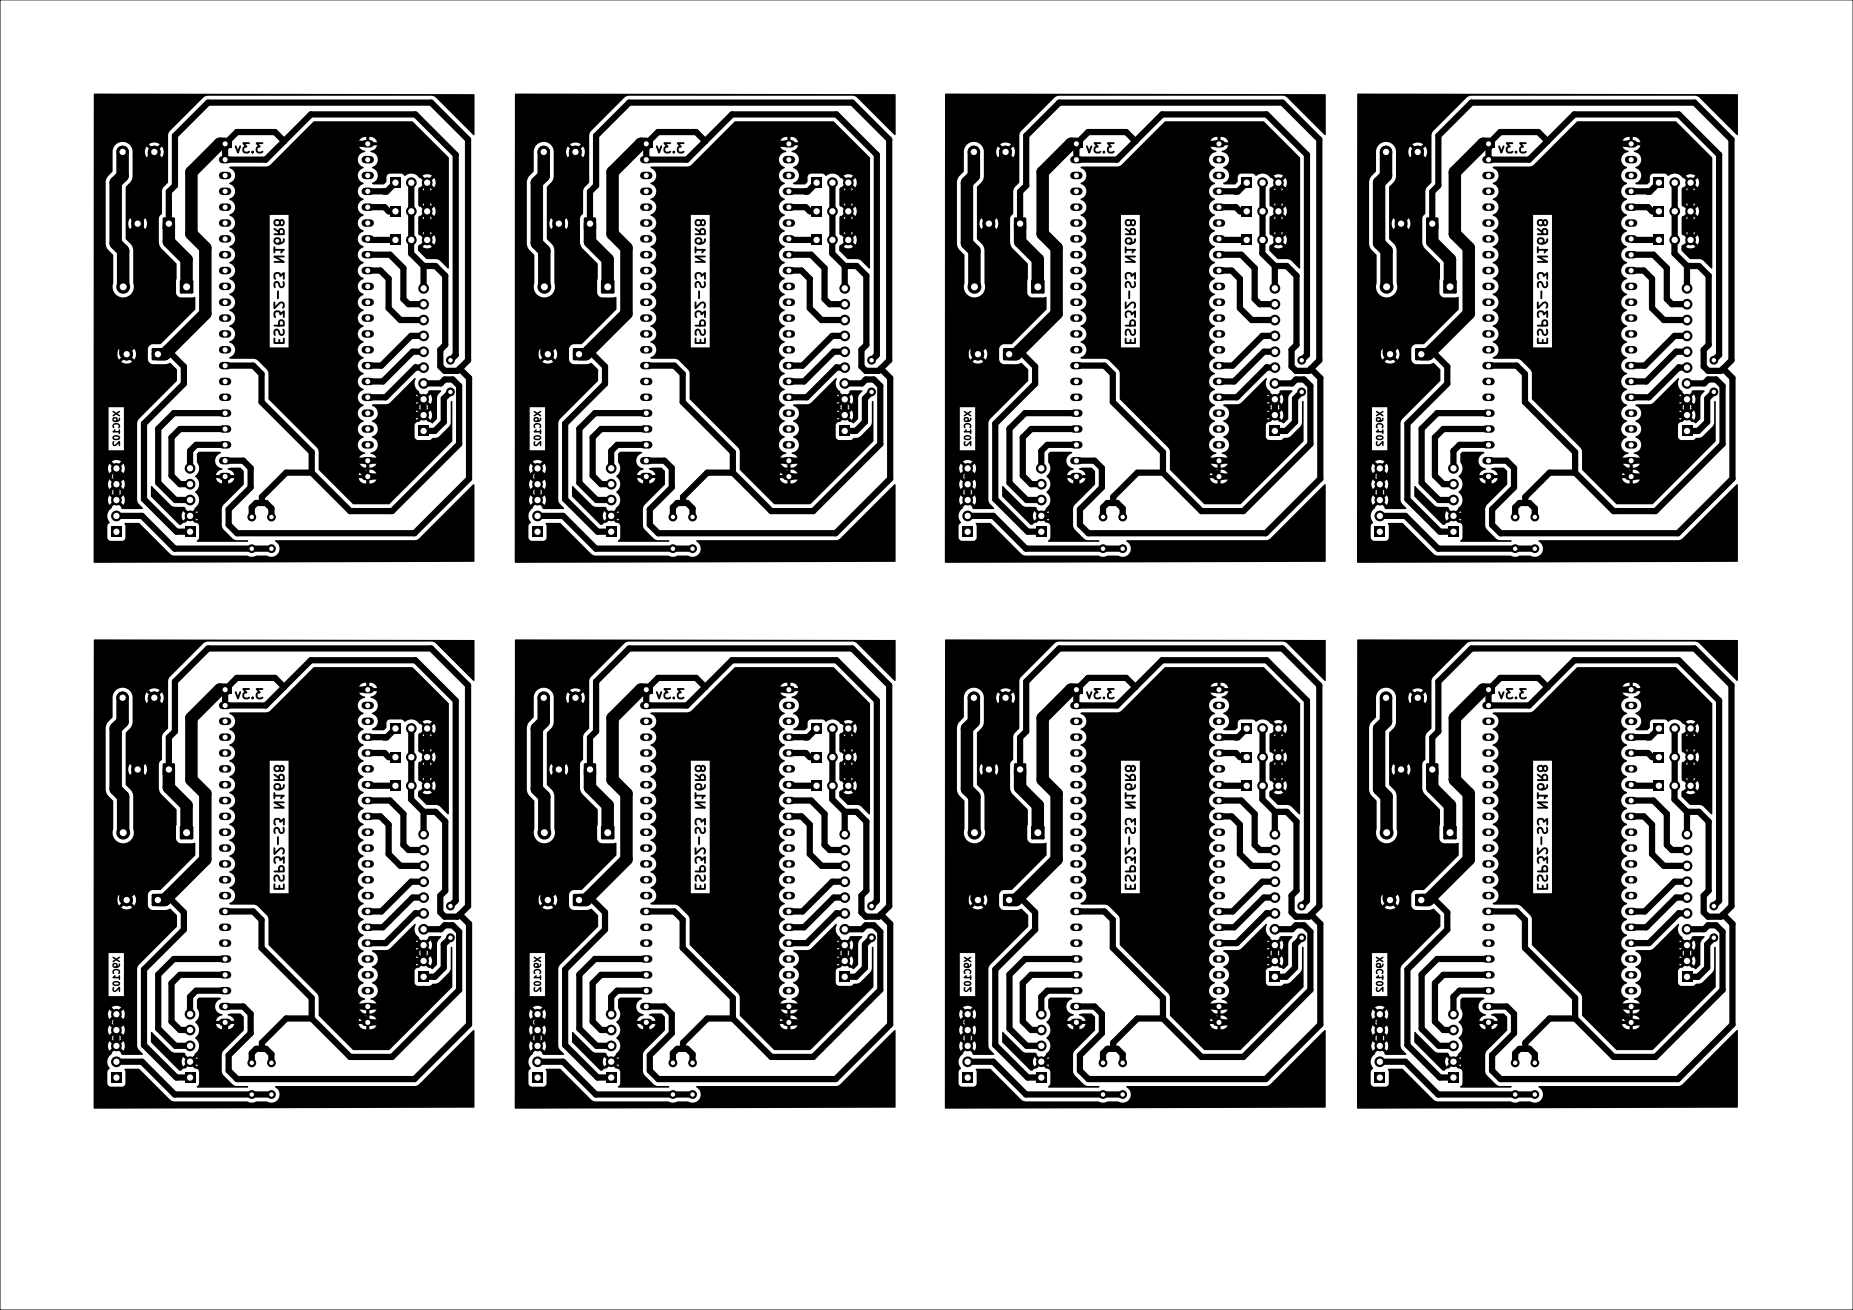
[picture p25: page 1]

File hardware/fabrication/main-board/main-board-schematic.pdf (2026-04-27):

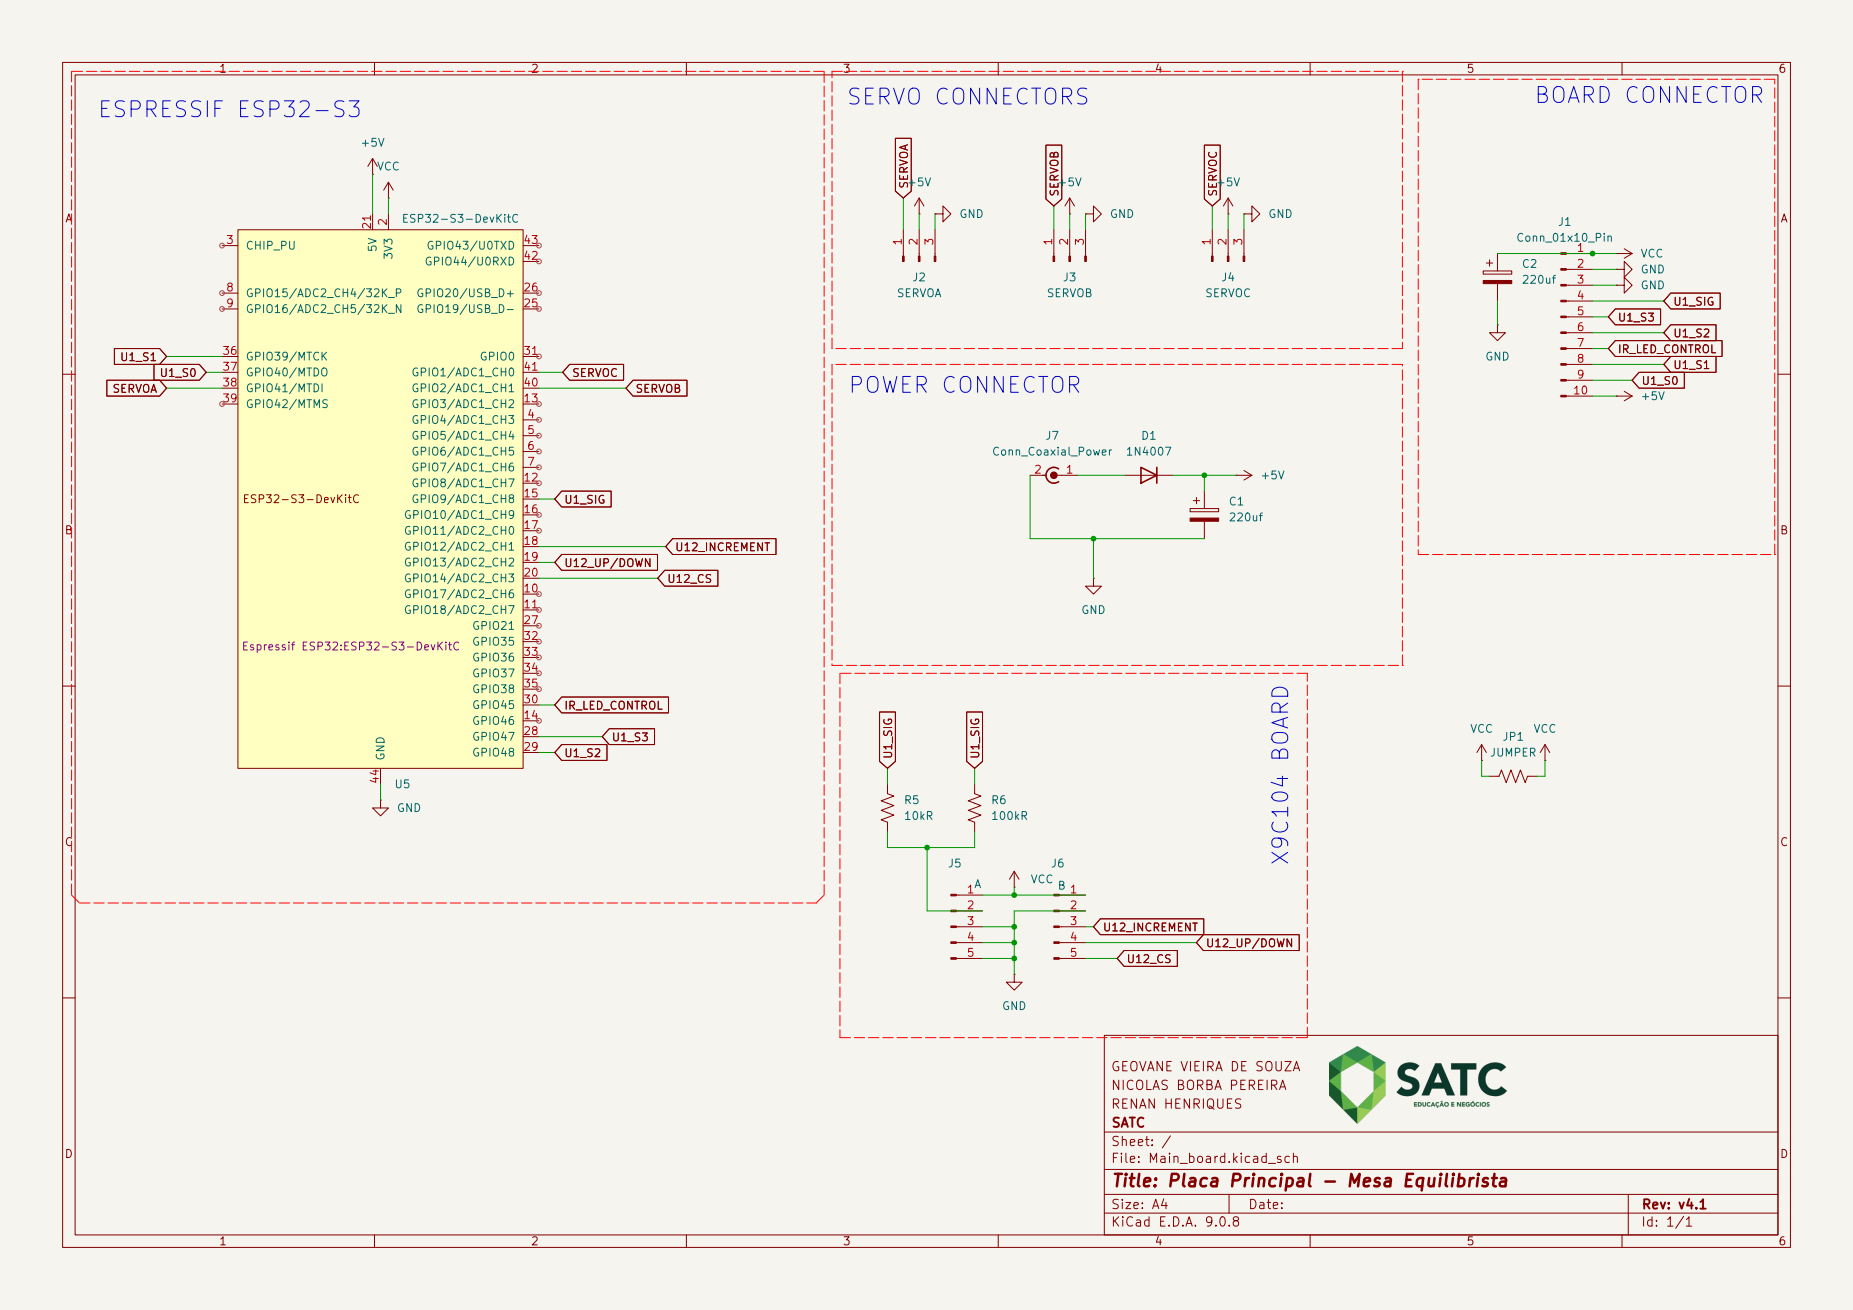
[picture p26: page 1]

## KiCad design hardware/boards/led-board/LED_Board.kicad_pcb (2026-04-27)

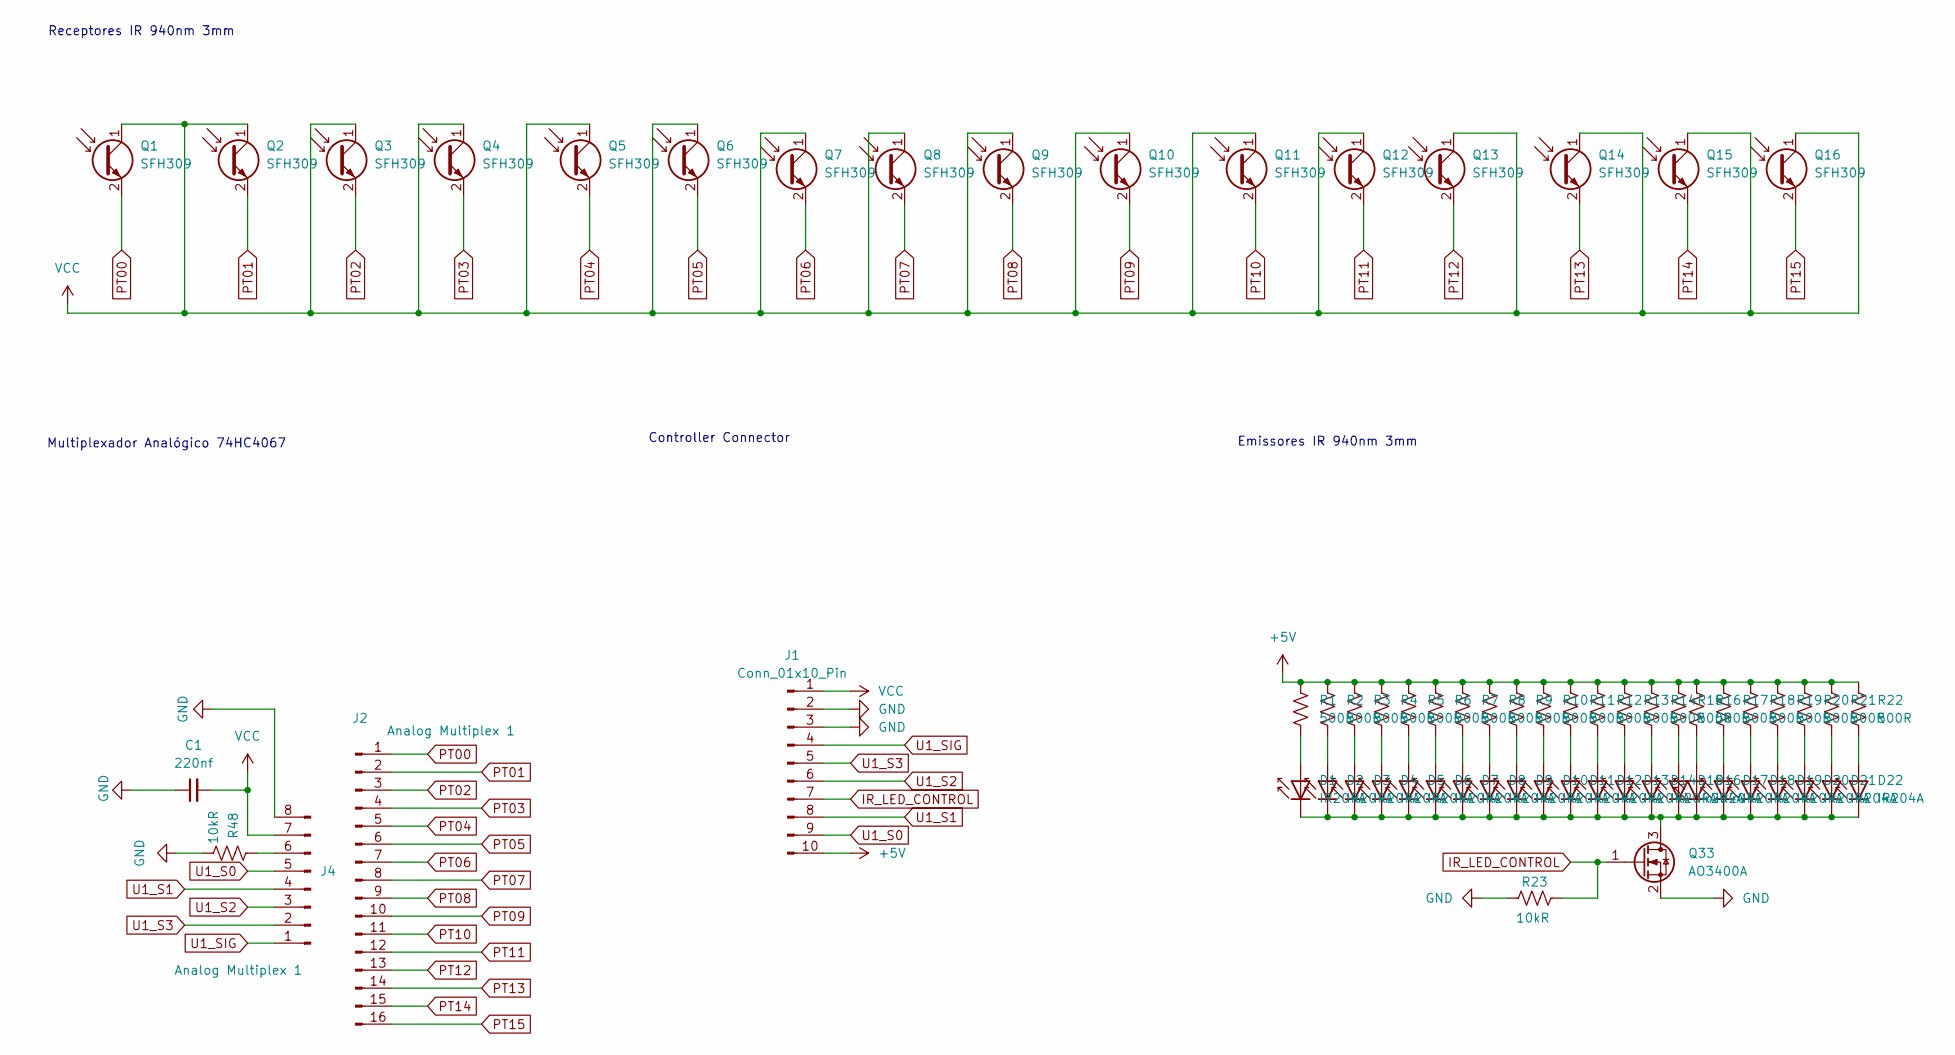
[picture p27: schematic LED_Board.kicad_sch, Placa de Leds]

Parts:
C1: 220nf; C_Disc_D7.5mm_W5.0mm_P10.00mm
D1, D2, D3, D4, D5, D6, D7, D8, D9, D10, D11, D12, D13, D14, D15, D16, D17, D18, D19, D20, D21, D22: IR204A; LED_D3.0mm_IRBlack
J1: Conn_01x10_Pin; PinSocket_1x10_P2.54mm_Vertical
J2: Analog Multiplex 1; PinHeader_1x16_P2.54mm_Vertical
J4: Analog Multiplex 1; PinHeader_1x08_P2.54mm_Vertical
Q1, Q2, Q3, Q4, Q5, Q6, Q7, Q8, Q9, Q10, Q11, Q12, Q13, Q14, Q15, Q16: SFH309; LED_D3.0mm_Clear
Q33: AO3400A; SOT-23
R1, R2, R3, R4, R5, R6, R7, R8, R9, R10, R11, R12, R13, R14, R15, R16, R17, R18, R19, R20, R21, R22: 500R; R_Axial_DIN0204_L3.6mm_D1.6mm_P5.08mm_Horizontal
R23, R48: 10kR; R_Axial_DIN0204_L3.6mm_D1.6mm_P5.08mm_Horizontal

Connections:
+5V: J1.10, R1.1, R2.1, R3.1, R4.1, R5.1, R6.1, R7.1, R8.1, R9.1, R10.1, R11.1, R12.1, R13.1, R14.1, R15.1, R16.1, R17.1, R18.1, R19.1, R20.1, R21.1, R22.1
GND: C1.1, J1.2, J1.3, J4.8, Q33.2 (S), R23.1, R48.2
IR_LED_CONTROL: J1.7, Q33.1 (G), R23.2
unnamed: D1.2 (A), R1.2
unnamed: D1.1 (K), D2.1 (K), D3.1 (K), D4.1 (K), D5.1 (K), D6.1 (K), D7.1 (K), D8.1 (K), D9.1 (K), D10.1 (K), D11.1 (K), D12.1 (K), D13.1 (K), D14.1 (K), D15.1 (K), D16.1 (K), D17.1 (K), D18.1 (K), D19.1 (K), D20.1 (K), D21.1 (K), D22.1 (K), Q33.3 (D)
unnamed: D2.2 (A), R2.2
unnamed: D3.2 (A), R3.2
unnamed: D4.2 (A), R4.2
unnamed: D5.2 (A), R5.2
unnamed: D6.2 (A), R6.2
unnamed: D7.2 (A), R7.2
unnamed: D8.2 (A), R8.2
unnamed: D9.2 (A), R9.2
unnamed: D10.2 (A), R10.2
unnamed: D11.2 (A), R11.2
unnamed: D12.2 (A), R12.2
unnamed: D13.2 (A), R13.2
unnamed: D14.2 (A), R14.2
unnamed: D15.2 (A), R15.2
unnamed: D16.2 (A), R16.2
unnamed: D17.2 (A), R17.2
unnamed: D18.2 (A), R18.2
unnamed: D19.2 (A), R19.2
unnamed: D20.2 (A), R20.2
unnamed: D21.2 (A), R21.2
unnamed: D22.2 (A), R22.2
unnamed: J4.6, R48.1
PT00: J2.1, Q1.2 (E)
PT01: J2.2, Q2.2 (E)
PT02: J2.3, Q3.2 (E)
PT03: J2.4, Q4.2 (E)
PT04: J2.5, Q5.2 (E)
PT05: J2.6, Q6.2 (E)
PT06: J2.7, Q7.2 (E)
PT07: J2.8, Q8.2 (E)
PT08: J2.9, Q9.2 (E)
PT09: J2.10, Q10.2 (E)
PT10: J2.11, Q11.2 (E)
PT11: J2.12, Q12.2 (E)
PT12: J2.13, Q13.2 (E)
PT13: J2.14, Q14.2 (E)
PT14: J2.15, Q15.2 (E)
PT15: J2.16, Q16.2 (E)
U1_S0: J1.9, J4.5
U1_S1: J1.8, J4.4
U1_S2: J1.6, J4.3
U1_S3: J1.5, J4.2
U1_SIG: J1.4, J4.1
VCC: C1.2, J1.1, J4.7, Q1.1 (C), Q2.1 (C), Q3.1 (C), Q4.1 (C), Q5.1 (C), Q6.1 (C), Q7.1 (C), Q8.1 (C), Q9.1 (C), Q10.1 (C), Q11.1 (C), Q12.1 (C), Q13.1 (C), Q14.1 (C), Q15.1 (C), Q16.1 (C)

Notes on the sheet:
Receptores IR 940nm 3mm
Controller Connector
Emissores IR 940nm 3mm
Multiplexador Analógico 74HC4067

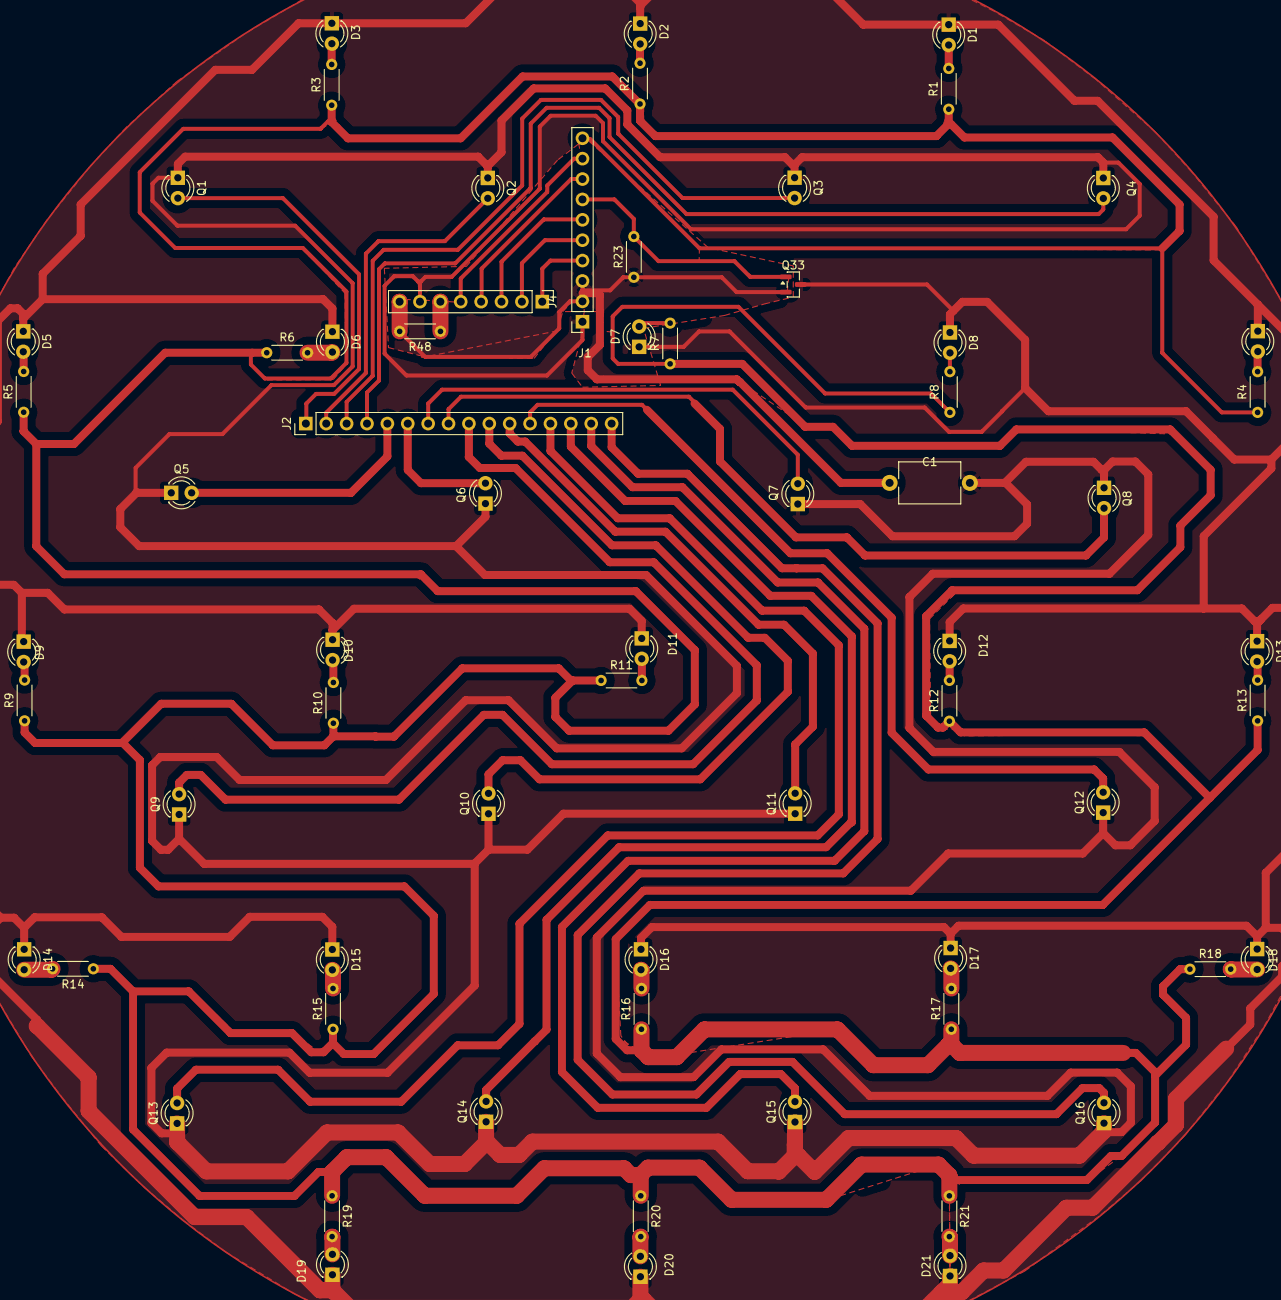
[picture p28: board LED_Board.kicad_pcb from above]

Board: 2 copper layers, 65 parts (0 on the bottom side), 48 nets.

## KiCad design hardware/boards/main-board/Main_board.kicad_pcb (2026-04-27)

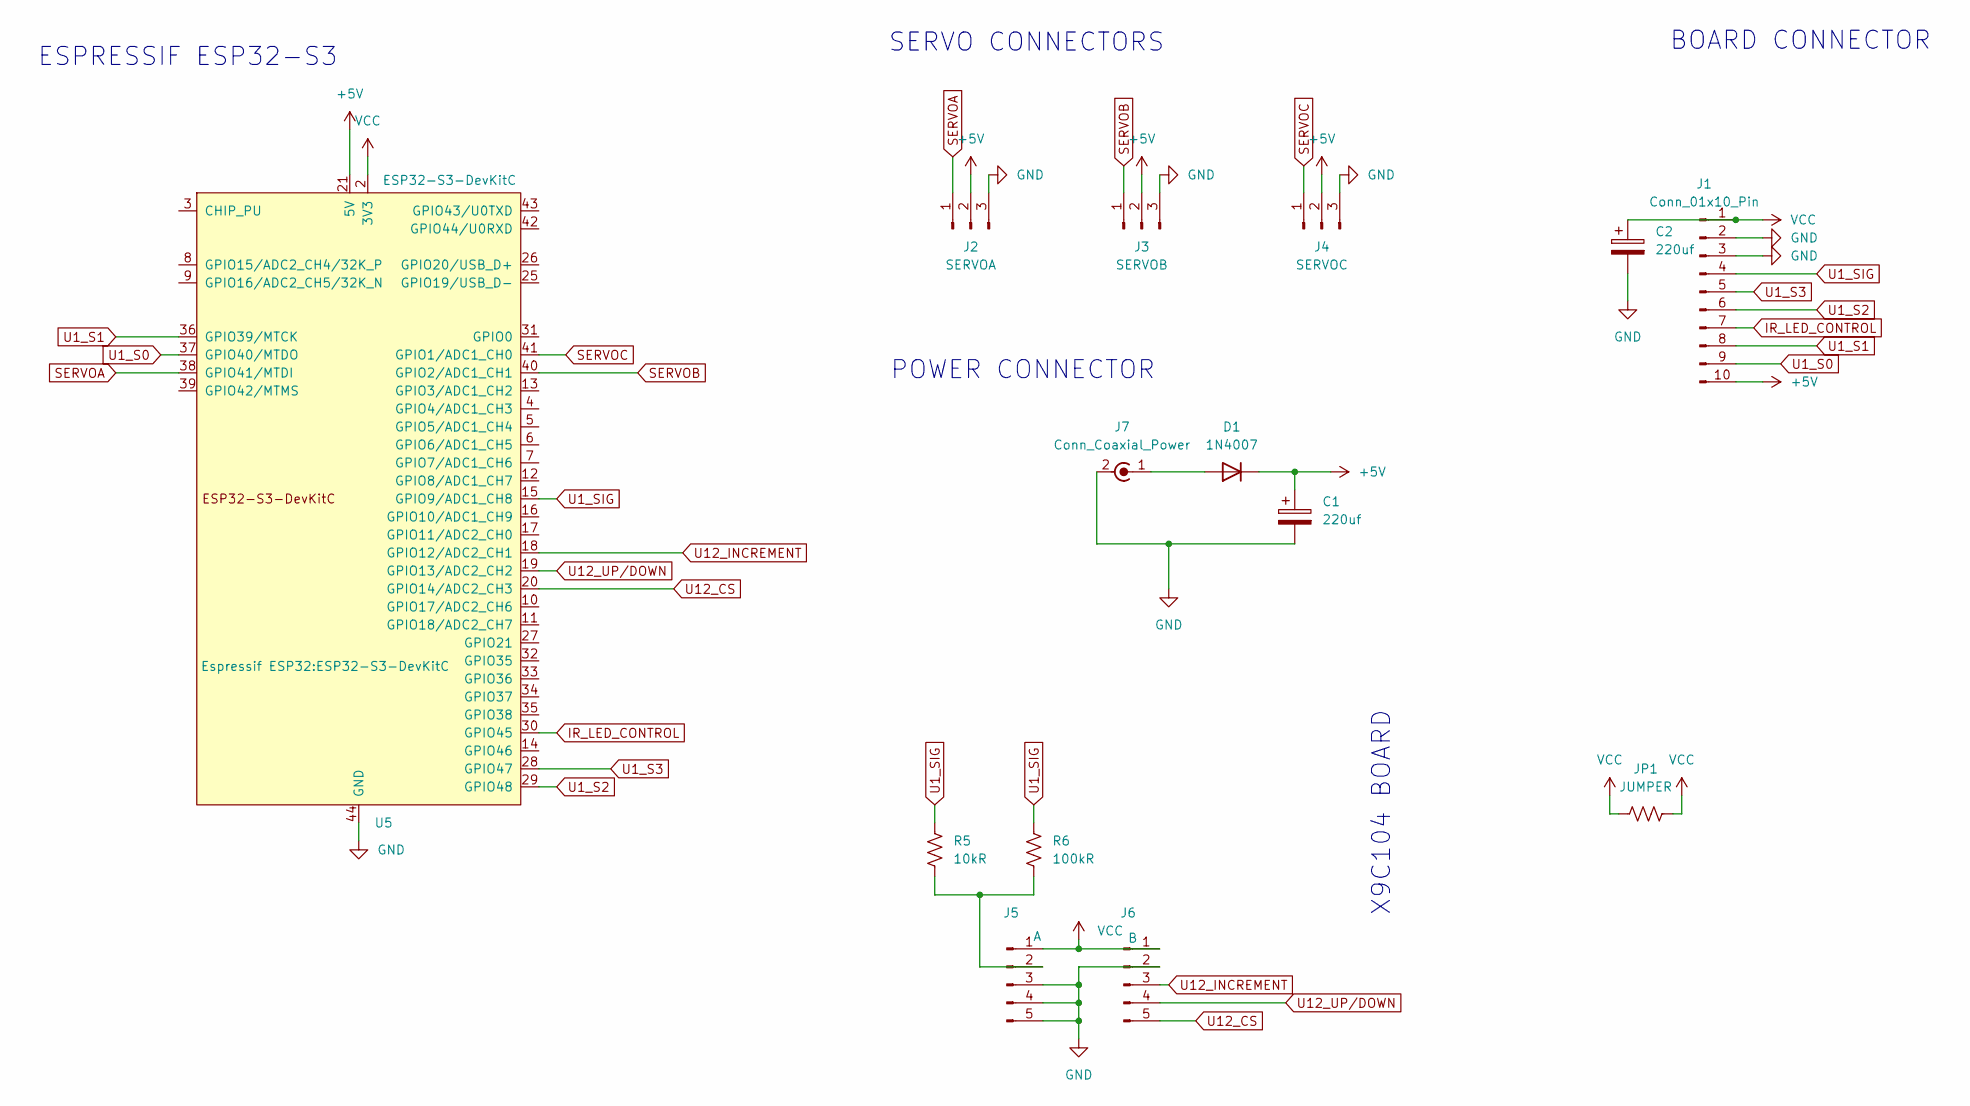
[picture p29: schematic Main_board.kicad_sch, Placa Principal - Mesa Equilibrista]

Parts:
C1, C2: 220uf; CP_Radial_D10.0mm_P5.00mm
D1: 1N4007; D_DO-41_SOD81_P10.16mm_Horizontal
J1: Conn_01x10_Pin; PinHeader_1x10_P2.54mm_Vertical
J2: SERVOA; PinHeader_1x03_P2.54mm_Vertical
J3: SERVOB; PinHeader_1x03_P2.54mm_Vertical
J4: SERVOC; PinHeader_1x03_P2.54mm_Vertical
J5: A; PinHeader_1x05_P2.54mm_Vertical
J6: B; PinHeader_1x05_P2.54mm_Vertical
J7: Conn_Coaxial_Power; L_Axial_L9.5mm_D4.0mm_P5.08mm_Vertical_Fastron_SMCC
JP1: JUMPER; R_Axial_DIN0204_L3.6mm_D1.6mm_P5.08mm_Horizontal
R5: 10kR; R_Axial_DIN0204_L3.6mm_D1.6mm_P5.08mm_Horizontal
R6: 100kR; R_Axial_DIN0204_L3.6mm_D1.6mm_P5.08mm_Horizontal
U5: ESP32-S3-DevKitC

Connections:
+5V: C1.1, D1.1 (K), J1.10, J2.2, J3.2, J4.2, U5.21 (5V)
GND: C1.2, C2.2, J1.2, J1.3, J2.3, J3.3, J4.3, J5.3, J5.4, J5.5, J6.2, J7.2 (Ext), U5.22 (GND), U5.23 (GND), U5.24 (GND), U5.44 (GND)
IR_LED_CONTROL: J1.7, U5.30 (GPIO45)
unnamed: D1.2 (A), J7.1 (In)
unnamed: J5.2, R5.2, R6.2
SERVOA: J2.1, U5.38 (GPIO41/MTDI)
SERVOB: J3.1, U5.40 (GPIO2/ADC1_CH1)
SERVOC: J4.1, U5.41 (GPIO1/ADC1_CH0)
U1_S0: J1.9, U5.37 (GPIO40/MTDO)
U1_S1: J1.8, U5.36 (GPIO39/MTCK)
U1_S2: J1.6, U5.29 (GPIO48)
U1_S3: J1.5, U5.28 (GPIO47)
U1_SIG: J1.4, R5.1, R6.1, U5.15 (GPIO9/ADC1_CH8)
U12_CS: J6.5, U5.20 (GPIO14/ADC2_CH3)
U12_INCREMENT: J6.3, U5.18 (GPIO12/ADC2_CH1)
U12_UP/DOWN: J6.4, U5.19 (GPIO13/ADC2_CH2)
VCC: C2.1, J1.1, J5.1, J6.1, JP1.1, JP1.2, U5.1 (3V3), U5.2 (3V3)

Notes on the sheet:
X9C104 BOARD
ESPRESSIF ESP32-S3
SERVO CONNECTORS
BOARD CONNECTOR
POWER CONNECTOR

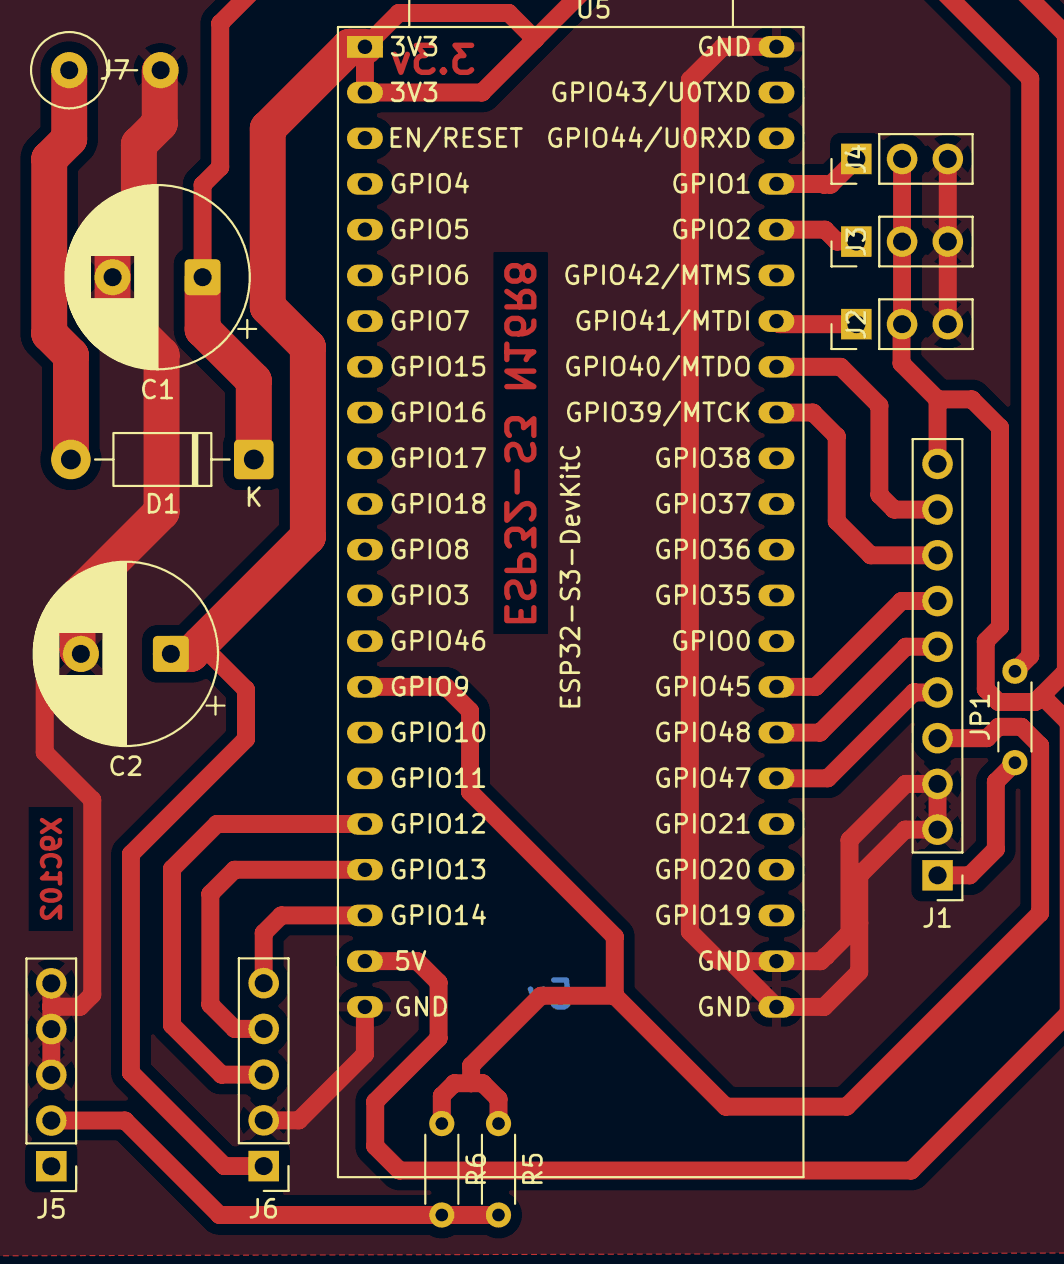
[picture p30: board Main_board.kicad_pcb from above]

Board: 2 copper layers, 14 parts (0 on the bottom side), 17 nets.

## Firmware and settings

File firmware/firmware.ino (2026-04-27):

#include <cstring>
#include <math.h>

#include "src/BoardConfig.h"
#include "src/DebugLogger.h"
#include "src/IRSensorArray.h"
#include "src/PlatformControl.h"
#include "src/RuntimeState.h"
#include "src/WebUiServer.h"
#include "src/X9C104Digipot.h"

namespace {

#if defined(ARDUINO_ARCH_ESP32)
HardwareSerial &kDebugPort = Serial0;
#else
decltype(Serial) &kDebugPort = Serial;
#endif

enum CalibServo {
  CALIB_A,
  CALIB_B,
  CALIB_C,
  CALIB_DONE
};

enum ButtonPress {
  NO_PRESS,
  SINGLE_PRESS,
  DOUBLE_PRESS,
  TRIPLE_PRESS,
  QUAD_PRESS,
  LONG_PRESS
};

enum StartupRiskStage : uint8_t {
  STARTUP_RISK_NONE = 0,
  STARTUP_RISK_PLATFORM_BEGIN = 1,
  STARTUP_RISK_DIGIPOT_RESTORE = 2
};

enum StartupSequenceStep : uint8_t {
  STARTUP_STEP_PLATFORM = 0,
  STARTUP_STEP_DIGIPOT = 1,
  STARTUP_STEP_SENSORS = 2,
  STARTUP_STEP_COMPLETE = 3
};

enum PidAutotunePhase : uint8_t {
  AUTOTUNE_IDLE,
  AUTOTUNE_WAITING_FOR_BALL_ENTRY,
  AUTOTUNE_TESTING_CANDIDATE,
  AUTOTUNE_SCORING_TRIAL,
  AUTOTUNE_CHOOSING_NEXT_CANDIDATE,
  AUTOTUNE_APPLYING,
  AUTOTUNE_COMPLETE,
  AUTOTUNE_FAILED
};

enum PidAutotuneStage : uint8_t {
  AUTOTUNE_STAGE_BASELINE,
  AUTOTUNE_STAGE_CMAES,
  AUTOTUNE_STAGE_TUNE_I
};

struct PidAutotuneCandidate {
  float p;
  float i;
  float d;
};

struct PidAutotuneMetrics {
  float score;
  float overshoot;
  float settlingTimeMs;
  float averageError;
  float entrySpeed;
  float captureTimeMs;
  float averageRadius;
  uint8_t captures;
  uint8_t misses;
  bool unsafe;
};

struct PidAutotuneHistory {
  PidAutotuneCandidate candidate;
  PidAutotuneMetrics metrics;
};


enum PidAutotuneRelayAxis : uint8_t {
  RELAY_AXIS_NONE,
  RELAY_AXIS_X,
  RELAY_AXIS_Y
};

struct PidAutotuneRelayMetrics {
  float ku;
  float puCycles;
  float observedAmplitude;
  uint8_t crossings;
  bool valid;
};

struct PidAutotuneStationarySample {
  float x;
  float y;
  float radius;
  float speed;
};

struct PidAutotuneStationaryMetrics {
  float meanCenterX;
  float meanCenterY;
  float meanRadius;
  float meanSpeed;
  float peakSpeed;
  float centerSpanX;
  float centerSpanY;
  float radiusSpread;
  float outwardDrift;
  uint8_t sampleCount;
  bool valid;
};

enum PidAutotuneAbortReason : uint8_t {
  AUTOTUNE_ABORT_NONE,
  AUTOTUNE_ABORT_BALL_LOST,
  AUTOTUNE_ABORT_RADIUS_LIMIT,
  AUTOTUNE_ABORT_SPEED_LIMIT,
  AUTOTUNE_ABORT_NOT_SETTLED,
  AUTOTUNE_ABORT_NO_CROSSINGS
};

babot::IRSensorArray gIrSensors(babot::kBoardPins);
babot::PlatformControl gPlatform(babot::kBoardPins);
babot::X9C104Digipot gDigipot(babot::kBoardPins.digipotCsPin,
                              babot::kBoardPins.digipotIncrementPin,
                              babot::kBoardPins.digipotUpDownPin);
babot::SharedState gSharedState;
babot::DebugLogger gDebugLogger;
babot::WebUiServer gWebUi(gSharedState, gDebugLogger);

babot::BaBotMode gMode = babot::ON;
babot::RuntimeConfig gConfig = babot::defaultRuntimeConfig();
babot::SystemStatus gSystemStatus = babot::defaultSystemStatus();
babot::TelemetryState gTelemetry{};

CalibServo gCalibServo = CALIB_A;
float gCenterX = 0.0f;
float gCenterY = 0.0f;
float gLastErrorX = 0.0f;
float gLastErrorY = 0.0f;
float gIntegralX = 0.0f;
float gIntegralY = 0.0f;
float gErrorX = 0.0f;
float gErrorY = 0.0f;
float gPlateRoll = 0.0f;
float gPlatePitch = 0.0f;
float gRawPlateRoll = 0.0f;
float gRawPlatePitch = 0.0f;
float gSmoothRoll = 0.0f;
float gSmoothPitch = 0.0f;
int gSkipCounter = 0;
unsigned long gTestStartTime = 0;
uint8_t gSelectedTestServo = 0;
int8_t gPositionTestMux = -1;
uint8_t gBallMissingCycles = 0;
bool gBallDetectionGraceActive = false;

bool gBallDetected = false;
bool gLastLoggedBallDetected = false;
bool gBallWasOnPlate = false;
bool gStartupComplete = false;
bool gWebTaskOwnsDebugFlush = false;
unsigned long gBallLostTime = 0;
unsigned long gButtonDownTime = 0;
unsigned long gLastPressTime = 0;
unsigned long gBootGuardStartTime = 0;
unsigned long gLastDebugSnapshotMs = 0;
int gPressCount = 0;
bool gButtonArmed = false;
ButtonPress gLatchedPress = NO_PRESS;
StartupSequenceStep gStartupStep = STARTUP_STEP_PLATFORM;
StartupRiskStage gRecoveredRiskStage = STARTUP_RISK_NONE;

int gCalibrationOffsetA = babot::kServoOffsetDefault;
int gCalibrationOffsetB = babot::kServoOffsetDefault;
int gCalibrationOffsetC = babot::kServoOffsetDefault;

constexpr uint8_t kPidAutotuneIValueCount = 4;
constexpr uint8_t kPidAutotuneTrialsPerCandidate = 3;
constexpr uint16_t kPidAutotuneTrialCycles = 120;
constexpr uint16_t kPidAutotuneIgnoreCycles = 5;
constexpr uint16_t kPidAutotuneCaptureHoldCycles = 12;
constexpr float kPidAutotuneSafeTiltDeg = 10.0f;
constexpr float kPidAutotuneCaptureRadius = 0.22f;
constexpr float kPidAutotuneNearCaptureRadius = 0.38f;
constexpr float kPidAutotuneMinP = 0.5f;
constexpr float kPidAutotuneMaxP = 12.0f;
constexpr float kPidAutotuneMinI = 0.0f;
constexpr float kPidAutotuneMaxI = 0.04f;
constexpr float kPidAutotuneMinD = 2.0f;
constexpr float kPidAutotuneMaxD = 60.0f;
constexpr float kPidAutotuneDuplicateTolerance = 0.03f;
constexpr float kPidAutotuneImprovementEpsilon = 0.01f;
constexpr uint16_t kPidAutotuneMaxEvaluations = 1024;

constexpr float kCaptureReleaseRadius = 0.55f;
constexpr float kCaptureReleaseSpeed = 0.08f;
constexpr float kCaptureReleaseInwardRate = -0.04f;

constexpr uint16_t kDefaultCaptureMaxCycles = 10;
constexpr uint16_t kCaptureMinCycles = 2;
constexpr float kDefaultCaptureTriggerRadius = 1.15f;
constexpr float kDefaultCaptureTriggerSpeed = 0.18f;
constexpr float kDefaultCapturePositionGain = 14.0f;
constexpr float kDefaultCaptureVelocityGain = 32.0f;
constexpr float kCaptureTriggerOutwardRate = 0.03f;

PidAutotunePhase gPidAutotunePhase = AUTOTUNE_IDLE;
PidAutotuneStage gPidAutotuneStage = AUTOTUNE_STAGE_BASELINE;
PidAutotuneCandidate gPidAutotuneQueue[kPidAutotuneMaxEvaluations] = {};
PidAutotuneHistory gPidAutotuneHistory[kPidAutotuneMaxEvaluations] = {};
PidAutotuneCandidate gPidAutotunePreviousGains = {0.0f, 0.0f, 0.0f};
PidAutotuneCandidate gPidAutotuneBestGains = {0.0f, 0.0f, 0.0f};
PidAutotuneCandidate gPidAutotuneNextGains = {0.0f, 0.0f, 0.0f};
PidAutotuneMetrics gPidAutotuneCurrentMetrics = {0.0f, 0.0f, 0.0f, 0.0f, 0.0f, 0.0f, 0.0f, 0, 0, false};
PidAutotuneMetrics gPidAutotuneBestMetrics = {999999.0f, 0.0f, 0.0f, 0.0f, 0.0f, 0.0f, 0.0f, 0, 0, false};
PidAutotuneMetrics gPidAutotuneBaselineMetrics = {999999.0f, 0.0f, 0.0f, 0.0f, 0.0f, 0.0f, 0.0f, 0, 0, false};
PidAutotuneMetrics gPidAutotunePdReferenceMetrics = {999999.0f, 0.0f, 0.0f, 0.0f, 0.0f, 0.0f, 0.0f, 0, 0, false};
PidAutotuneCandidate gPidAutotunePdBestGains = {0.0f, 0.0f, 0.0f};
float gPidAutotuneNoiseFloor = 0.0f;
float gPidAutotuneNoiseSum = 0.0f;
uint8_t gPidAutotuneSafetyAborts = 0;

uint8_t gPidAutotuneIIndex = 0;
float gPidAutotuneBaseSetpointX = 0.0f;
float gPidAutotuneBaseSetpointY = 0.0f;
float gPidAutotuneErrorSum = 0.0f;
float gPidAutotuneRadiusSum = 0.0f;
float gPidAutotunePreviousCenterX = 0.0f;
float gPidAutotunePreviousCenterY = 0.0f;
float gPidAutotuneVelocitySum = 0.0f;
float gPidAutotunePeakVelocity = 0.0f;
uint16_t gPidAutotunePhaseCycles = 0;
uint16_t gPidAutotuneCaptureCycles = 0;
uint16_t gPidAutotuneSampleCycles = 0;
uint16_t gPidAutotuneEvaluationIndex = 0;
uint8_t gPidAutotuneQueuedCount = 0;
uint8_t gPidAutotuneTrial = 0;
uint8_t gPidAutotuneLossCycles = 0;
uint8_t gPidAutotuneSaturationCycles = 0;
uint16_t gPidAutotuneExplorationStep = 0;
bool gPidAutotuneHasBest = false;
bool gPidAutotuneHasBaseline = false;
bool gPidAutotuneHasPrevious = false;
bool gPidAutotuneTrialHadBall = false;
char gPidAutotuneLastFailure[babot::kStatusTextCapacity] = "";

// CMA-ES optimizer state
#include "src/CmaEsOptimizer.h"
CmaEsState gCmaEs = {};
float gCmaEsGenerationScores[kCmaEsLambda] = {};
uint8_t gCmaEsLambdaIndex = 0;  // How many of the current generation have been scored

bool isPinAssigned(int pin) {
  return babot::isPinAssigned(pin);
}

void resetClosedLoopState();
uint8_t pidAutotuneProgress();
bool pidAutotuneActive();
void failPidAutotune(const char *reason);
void cancelPidAutotune(const char *reason);

#include "src/ButtonInput.h"
#include "src/ControlLoop.h"
#include "src/PidAutotune.h"

void setMode(babot::BaBotMode mode);

#include "src/StartupManager.h"
#include "src/ModeHandlers.h"
#include "src/UiCommandHandler.h"

}

void setup() {

  kDebugPort.begin(babot::kDebugBaudRate);
  delay(50);
  bootPrint("BOOT 01: serial ready");

  if (isFirstBootAfterFlash()) {
    bootPrint("BOOT 01A: first boot detected - resetting all NVS to defaults");
    performFactoryReset();
  }

  if (isPinAssigned(babot::kBoardPins.buttonPin)) {
    pinMode(babot::kBoardPins.buttonPin, INPUT_PULLUP);
  }
  bootCheckpoint("BOOT 02: button pin configured", makeColor(16, 16, 16));

  bootCheckpoint("BOOT 03: RGB LED driver ready", makeColor(0, 0, 32));

  if (isPinAssigned(babot::kBoardPins.buttonPin)) {
    updateSubsystemStatus("button", gSystemStatus.button, babot::READY, "Boot button available.");
  } else {
    updateSubsystemStatus("button", gSystemStatus.button, babot::SUBSYSTEM_DISABLED, "Button pin not assigned.");
  }

  if (isPinAssigned(babot::kBoardPins.irLedPin)) {
    pinMode(babot::kBoardPins.irLedPin, INPUT_PULLUP);
  }

  if (babot::kWaitForDebugSerialOnBootMs > 0) {
    delay(babot::kWaitForDebugSerialOnBootMs);
  }
  bootCheckpoint("BOOT 04: post-serial delay complete", makeColor(0, 16, 16));

  gDebugLogger.begin(kDebugPort);
  gDebugLogger.tryLog("Boot start.");
  bootCheckpoint("BOOT 05: debug logger ready", makeColor(0, 32, 32));

  gSystemStatus = babot::defaultSystemStatus();
  updateSubsystemStatus("button",
                        gSystemStatus.button,
                        isPinAssigned(babot::kBoardPins.buttonPin) ? babot::READY : babot::SUBSYSTEM_DISABLED,
                        isPinAssigned(babot::kBoardPins.buttonPin) ? "Boot button available." : "Button pin not assigned.");

  gRecoveredRiskStage = readPendingRiskStage();
  clearPendingRiskStage();
  applyRecoveredBootPolicy();

  setStartupPhaseWithLog(babot::STARTUP_SAFE_BOOT, "Loading persisted runtime state");
  const bool storageAvailable = gSharedState.loadRuntimeConfig(gConfig);
  updateSubsystemStatus("storage",
                        gSystemStatus.storage,
                        storageAvailable ? babot::READY : babot::DEGRADED,
                        storageAvailable ? "Runtime configuration loaded from NVS."
                                         : "Runtime configuration unavailable; using defaults.",
                        !storageAvailable);

  bootPrintf("BOOT 06: runtime config loaded digipot=%u", static_cast<unsigned>(gConfig.digipotTap));
  gDebugLogger.tryLogf("Runtime config loaded. Digipot=%u",
                       static_cast<unsigned>(gConfig.digipotTap));
  bootCheckpoint("BOOT 07: runtime config applied", makeColor(16, 32, 0));

  bootPrint("BOOT 08A: shared state begin");
  if (!gSharedState.begin(gConfig)) {
    bootPrint("BOOT 08E: shared state init failed");
    gDebugLogger.tryLog("Shared state initialization failed.");
    setSystemAlertWithLog("Shared state initialization failed; Web UI commands may be unavailable.");
  }
  bootCheckpoint("BOOT 08B: shared state begin complete", makeColor(32, 0, 0));
  publishAllState();

  setStartupPhaseWithLog(babot::STARTUP_NETWORK, "Starting Wi-Fi AP and Web UI");
  bootPrint("BOOT 09A: web UI begin");
  gWebTaskOwnsDebugFlush = gWebUi.begin();
  if (gWebTaskOwnsDebugFlush) {
    updateSubsystemStatus("wifiAp", gSystemStatus.wifiAp, babot::READY, "Wi-Fi AP started.");
    updateSubsystemStatus("webUi", gSystemStatus.webUi, babot::READY, "Async Web UI running.");
    bootCheckpoint("BOOT 09B: web UI begin complete", makeColor(0, 32, 8));
    gDebugLogger.tryLog("Async Web UI started; serial debug flush moved to Wi-Fi core.");
  } else {
    updateSubsystemStatus("wifiAp", gSystemStatus.wifiAp, babot::FAILED, "Wi-Fi AP or web task failed to start.", true);
    updateSubsystemStatus("webUi", gSystemStatus.webUi, babot::FAILED, "Web UI unavailable; staying in serial-only mode.");
    bootPrint("BOOT 09E: web UI begin failed");
    gDebugLogger.tryLog("Web UI task failed; falling back to direct-loop debug flushing.");
    gDebugLogger.flushDirect();
  }

  gBootGuardStartTime = millis();
  bootCheckpoint("BOOT 10: safe boot complete, deferred startup queued", makeColor(0, 48, 0));
  publishAllState();
}

void loop() {
  const ButtonPress press = checkButton(gMode == babot::CALIBRATION);
  if (press != NO_PRESS) {
    gLatchedPress = press;
    gDebugLogger.tryLogf("Button event: %s", buttonPressToString(press));
  }

  applyModeSwitching(press);
  drainUiCommands();

  if (!gStartupComplete) {
    advanceStartupSequence();
    if (!gWebTaskOwnsDebugFlush) {
      gDebugLogger.flushDirect();
    }
    gLatchedPress = NO_PRESS;
    delay(1);
    return;
  }

  if (xSemaphoreTake(gIrSensors.measurementReady, 0) != pdTRUE) {
    return;
  }

  gDigipot.setTap(gConfig.digipotTap);

  if (gMode != babot::POSITION_TEST) {
    const bool previousBallDetected = gBallDetected;
    const bool rawBallDetected = gIrSensors.ballOnPlate(gConfig.ballThreshold);
    float rawX = 0.0f;
    float rawY = 0.0f;
    if (rawBallDetected) {
      gBallDetected = true;
      gBallDetectionGraceActive = false;
      gBallMissingCycles = 0;
      gIrSensors.calculateWeightedCenter(rawX, rawY, gConfig.ballThreshold);
      if (!previousBallDetected) {
        gCenterX = rawX;
        gCenterY = rawY;
      } else {
        gCenterX = babot::kBallPositionAlpha * rawX + (1.0f - babot::kBallPositionAlpha) * gCenterX;
        gCenterY = babot::kBallPositionAlpha * rawY + (1.0f - babot::kBallPositionAlpha) * gCenterY;
      }
    } else if (previousBallDetected && gBallMissingCycles < babot::kBallMissingDebounceCycles) {
      ++gBallMissingCycles;
      gBallDetected = true;
      gBallDetectionGraceActive = true;
    } else {
      gBallDetected = false;
      gBallDetectionGraceActive = false;
      gBallMissingCycles = 0;
    }

    if (previousBallDetected != gBallDetected || gLastLoggedBallDetected != gBallDetected) {
      gDebugLogger.tryLogf("Ball state changed: %s center=(%.2f,%.2f)",
                           gBallDetected ? "detected" : "missing",
                           gCenterX,
                           gCenterY);
      gLastLoggedBallDetected = gBallDetected;
    }
  }
  maybeQueueDebugSnapshot();

  if (pidAutotuneActive()) {
    handlePidAutotune();
    publishAllState();
    if (!gWebTaskOwnsDebugFlush) {
      gDebugLogger.flushDirect();
    }
    gLatchedPress = NO_PRESS;
    return;
  }

  switch (gMode) {
    case babot::ON:
      handleOnMode();
      break;

    case babot::OFF:
      resetClosedLoopState();
      movePlatformWithMotionGrace(0.0f, 0.0f, babot::kPlateHeightMm);
      break;

    case babot::ASSEMBLY:
      handleAssemblyMode();
      break;

    case babot::CALIBRATION:
      handleCalibrationMode(gLatchedPress);
      break;

    case babot::TEST:
      handleTestMode();
      break;

    case babot::INDIVIDUAL_TEST:
      handleIndividualTestMode();
      break;

    case babot::POSITION_TEST:
      handlePositionTestMode();
      break;
  }

  publishAllState();
  if (!gWebTaskOwnsDebugFlush) {
    gDebugLogger.flushDirect();
  }
  gLatchedPress = NO_PRESS;
}

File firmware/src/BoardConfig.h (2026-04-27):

#pragma once

#include <Arduino.h>

namespace babot {

constexpr int kUnassignedPin = -1;
constexpr size_t kSensorsPerMux = 16;
constexpr size_t kMuxCount = 1;
constexpr size_t kSensorCount = kSensorsPerMux * kMuxCount;

struct MuxPins {
  int s0;
  int s1;
  int s2;
  int s3;
  int sig;
};

struct BoardPins {
  int servoPinA;
  int servoPinB;
  int servoPinC;
  int irLedPin;
  int buttonPin;
  int digipotCsPin;
  int digipotIncrementPin;
  int digipotUpDownPin;
  MuxPins mux;
};

constexpr bool isPinAssigned(int pin) {
  return pin >= 0;
}

constexpr BoardPins kBoardPins = {
    41,
    2,
    1,
    45,
    0,
    14,
    12,
    13,
    {40, 39, 48, 47, 9},
};

constexpr unsigned long kDebugBaudRate = 115200;  // Serial baud rate used for debug logging and startup diagnostics.
constexpr unsigned long kLongPressTimeMs = 1000;  // Button hold duration required to classify a press as a long press.
constexpr unsigned long kDoublePressGapMs = 500;  // Maximum time gap used to group short button presses into multi-press gestures.
constexpr unsigned long kBallHoldTimeoutMs = 1000;  // Time to keep the last plate command after a previously detected ball disappears.
constexpr unsigned long kBootReleaseGuardMs = 250;  // Delay window that ignores a held boot button immediately after startup.
constexpr unsigned long kControlIntervalUs = 33333;  // Nominal control-loop period in microseconds (~30 Hz). Used as a timing reference for cycle-to-ms conversions; the actual loop is driven by the sensor state machine.
constexpr unsigned long kTelemetryBroadcastMs = 50;  // WebSocket state broadcast interval for the Web UI.
constexpr size_t kUiCommandQueueLength = 12;  // FreeRTOS queue depth for pending Web UI commands.
constexpr uint16_t kWebTaskStackSize = 8192;  // Stack size allocated to the async Web UI task.
constexpr UBaseType_t kWebTaskPriority = 1;  // FreeRTOS priority assigned to the Web UI task.
constexpr BaseType_t kWebTaskCore = 0;  // ESP32 core used to run the Web UI task.
constexpr uint16_t kSensorTaskStackSize = 4096;  // Stack size for the IR sensor measurement task.
constexpr UBaseType_t kSensorTaskPriority = 2;  // FreeRTOS priority for the sensor task (higher than web, lower than idle would starve it).
constexpr BaseType_t kSensorTaskCore = 1;  // ESP32 core for the sensor task (same as control loop for safe shared state access).
constexpr char kWifiApSsid[] = "12345678";  // SSID broadcast by the robot access point.
constexpr char kWifiApPassword[] = "12345678";  // Password required to connect to the robot access point.

constexpr float kProportionalGain = 1.5f;  // Default PID proportional gain applied to both ball-position axes.
constexpr float kIntegralGain = 0.0f;  // Default PID integral gain used to reduce steady-state position error.
constexpr float kDerivativeGain = 5.0f;  // Default PID derivative gain used to damp fast ball motion.
constexpr float kVelocityScale = 0.001f;  // Small scaling term that prevents derivative velocity normalization from dividing by zero.
constexpr float kIrAlpha = 0.8f;  // Exponential smoothing factor for per-channel IR signal readings.
constexpr float kBallPositionAlpha = 0.7f;  // Exponential smoothing factor for the calculated ball center position.
constexpr float kOutputSmoothingAlpha = 1.0f;  // Exponential smoothing factor for roll and pitch commands.
constexpr float kBallThreshold = 80.0f;  // Minimum IR signal range required to treat the ball as detected.
constexpr float kSensorGridScale = 1.0f;  // Reverted to legacy BaBot coordinate scale (-1.5 to 1.5).
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

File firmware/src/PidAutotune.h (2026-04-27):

#pragma once

// Forward declaration - defined further down in this file.
void chooseNextPidAutotuneCandidate();

uint8_t pidAutotuneProgress() {
  if (gPidAutotunePhase == AUTOTUNE_COMPLETE) {
    return 100;
  }
  if (gPidAutotunePhase == AUTOTUNE_IDLE || gPidAutotunePhase == AUTOTUNE_FAILED) {
    return 0;
  }
  if (gPidAutotunePhase == AUTOTUNE_APPLYING) {
    return 98;
  }
  if (gPidAutotuneStage == AUTOTUNE_STAGE_TUNE_I) {
    const uint16_t scaled = (static_cast<uint16_t>(gPidAutotuneIIndex) * 80) /
                            static_cast<uint16_t>(kPidAutotuneIValueCount);
    return static_cast<uint8_t>(min<uint16_t>(95, 15 + scaled));
  }
  if (!gPidAutotuneHasBaseline) {
    return 5;
  }
  // CMA-ES progress: estimate from generation and sigma convergence
  if (gPidAutotuneStage == AUTOTUNE_STAGE_CMAES) {
    const float genFrac = static_cast<float>(gCmaEs.generation) / static_cast<float>(kCmaEsMaxGenerations);
    const float sigmaFrac = 1.0f - (gCmaEs.sigma / kCmaEsInitialSigma);
    const float progress = max(genFrac, sigmaFrac) * 80.0f;
    return static_cast<uint8_t>(10 + min(progress, 80.0f));
  }
  return static_cast<uint8_t>(5 + (gPidAutotuneEvaluationIndex % 90));
}

bool pidAutotuneActive() {
  return gPidAutotunePhase != AUTOTUNE_IDLE &&
         gPidAutotunePhase != AUTOTUNE_COMPLETE &&
         gPidAutotunePhase != AUTOTUNE_FAILED;
}

void setPidAutotuneFailure(const char *reason) {
  const char *safeReason = (reason != nullptr) ? reason : "";
  strncpy(gPidAutotuneLastFailure, safeReason, sizeof(gPidAutotuneLastFailure) - 1);
  gPidAutotuneLastFailure[sizeof(gPidAutotuneLastFailure) - 1] = '\0';
}

void restorePidAutotuneBaseSetpoint() {
  gConfig.setpointX = gPidAutotuneBaseSetpointX;
  gConfig.setpointY = gPidAutotuneBaseSetpointY;
}

float currentAutotuneRadius() {
  const float dx = gPidAutotuneBaseSetpointX - gCenterX;
  const float dy = gPidAutotuneBaseSetpointY - gCenterY;
  return sqrtf(dx * dx + dy * dy);
}

PidAutotuneCandidate clampPidAutotuneCandidate(PidAutotuneCandidate candidate) {
  candidate.p = constrain(candidate.p, kPidAutotuneMinP, kPidAutotuneMaxP);
  candidate.i = constrain(candidate.i, kPidAutotuneMinI, kPidAutotuneMaxI);
  candidate.d = constrain(candidate.d, kPidAutotuneMinD, kPidAutotuneMaxD);
  return candidate;
}

bool pidAutotuneCandidatesClose(const PidAutotuneCandidate &a, const PidAutotuneCandidate &b) {
  return fabsf(a.p - b.p) <= kPidAutotuneDuplicateTolerance &&
         fabsf(a.i - b.i) <= kPidAutotuneDuplicateTolerance &&
         fabsf(a.d - b.d) <= kPidAutotuneDuplicateTolerance;
}

bool pidAutotuneCandidateSeen(const PidAutotuneCandidate &candidate) {
  for (uint8_t i = 0; i < gPidAutotuneQueuedCount; ++i) {
    if (pidAutotuneCandidatesClose(gPidAutotuneQueue[i], candidate)) {
      return true;
    }
  }
  const uint8_t historyCount = static_cast<uint8_t>(min<uint16_t>(gPidAutotuneEvaluationIndex, kPidAutotuneMaxEvaluations));
  for (uint8_t i = 0; i < historyCount; ++i) {
    if (pidAutotuneCandidatesClose(gPidAutotuneHistory[i].candidate, candidate)) {
      return true;
    }
  }
  return false;
}

bool enqueuePidAutotuneCandidate(PidAutotuneCandidate candidate) {
  if (gPidAutotuneQueuedCount >= kPidAutotuneMaxEvaluations) {
    return false;
  }
  candidate = clampPidAutotuneCandidate(candidate);
  if (pidAutotuneCandidateSeen(candidate)) {
    return false;
  }
  gPidAutotuneQueue[gPidAutotuneQueuedCount++] = candidate;
  return true;
}

bool dequeuePidAutotuneCandidate(PidAutotuneCandidate &candidate) {
  if (gPidAutotuneQueuedCount == 0) {
    return false;
  }
  candidate = gPidAutotuneQueue[0];
  for (uint8_t i = 1; i < gPidAutotuneQueuedCount; ++i) {
    gPidAutotuneQueue[i - 1] = gPidAutotuneQueue[i];
  }
  --gPidAutotuneQueuedCount;
  return true;
}

void resetPidAutotuneTrialMetrics() {
  gPidAutotuneErrorSum = 0.0f;
  gPidAutotuneRadiusSum = 0.0f;
  gPidAutotuneVelocitySum = 0.0f;
  gPidAutotunePeakVelocity = 0.0f;
  gPidAutotuneCaptureCycles = 0;
  gPidAutotuneSampleCycles = 0;
  gPidAutotuneLossCycles = 0;
  gPidAutotuneSaturationCycles = 0;
  gPidAutotuneTrialHadBall = false;
}

void beginPidAutotuneCandidate(const PidAutotuneCandidate &candidate) {
  gPidAutotuneNextGains = clampPidAutotuneCandidate(candidate);
  gConfig.pGain = gPidAutotuneNextGains.p;
  gConfig.iGain = gPidAutotuneNextGains.i;
  gConfig.dGain = gPidAutotuneNextGains.d;
  restorePidAutotuneBaseSetpoint();
  gPidAutotuneTrial = 0;
  gPidAutotuneCurrentMetrics = {999999.0f, 0.0f, 0.0f, 0.0f, 0.0f, 0.0f, 0.0f, 0, 0, false};
  gPidAutotunePhase = AUTOTUNE_WAITING_FOR_BALL_ENTRY;
  gPidAutotunePhaseCycles = 0;
  resetClosedLoopState();
  movePlatformWithMotionGrace(0.0f, 0.0f, babot::kPlateHeightMm);
}

void beginPidAutotuneTrial() {
  gConfig.pGain = gPidAutotuneNextGains.p;
  gConfig.iGain = gPidAutotuneNextGains.i;
  gConfig.dGain = gPidAutotuneNextGains.d;
  restorePidAutotuneBaseSetpoint();
  gPidAutotunePhase = AUTOTUNE_TESTING_CANDIDATE;
  gPidAutotunePhaseCycles = 0;
  resetPidAutotuneTrialMetrics();
  resetClosedLoopState();
  gPidAutotunePreviousCenterX = gCenterX;
  gPidAutotunePreviousCenterY = gCenterY;
}

void failPidAutotune(const char *reason) {
  setPidAutotuneFailure(reason);
  gPidAutotunePhase = AUTOTUNE_FAILED;
  gConfig.pGain = gPidAutotunePreviousGains.p;
  gConfig.iGain = gPidAutotunePreviousGains.i;
  gConfig.dGain = gPidAutotunePreviousGains.d;
  restorePidAutotuneBaseSetpoint();
  resetClosedLoopState();
  movePlatformWithMotionGrace(0.0f, 0.0f, babot::kPlateHeightMm);
}

void updatePidAutotuneTrialMetrics() {
  if (gPidAutotunePhaseCycles <= kPidAutotuneIgnoreCycles || !gBallDetected) {
    return;
  }

  const float radius = currentAutotuneRadius();
  const float stepX = gCenterX - gPidAutotunePreviousCenterX;
  const float stepY = gCenterY - gPidAutotunePreviousCenterY;
  const float speed = sqrtf(stepX * stepX + stepY * stepY);
  gPidAutotunePreviousCenterX = gCenterX;
  gPidAutotunePreviousCenterY = gCenterY;

  if (!gPidAutotuneTrialHadBall) {
    gPidAutotuneCurrentMetrics.entrySpeed = max(gPidAutotuneCurrentMetrics.entrySpeed, speed);
    gPidAutotuneTrialHadBall = true;
  }

  gPidAutotuneVelocitySum += speed;
  gPidAutotunePeakVelocity = max(gPidAutotunePeakVelocity, speed);
  gPidAutotuneRadiusSum += radius;
  ++gPidAutotuneSampleCycles;
  if (radius <= kPidAutotuneCaptureRadius) {
    ++gPidAutotuneCaptureCycles;
  } else {
    gPidAutotuneCaptureCycles = 0;
  }
}
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

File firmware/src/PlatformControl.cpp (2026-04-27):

#include "PlatformControl.h"

#include <math.h>

namespace babot {

namespace {

constexpr char kPreferencesNamespace[] = "babot";
constexpr char kServoOffsetAKey[] = "servo_a";
constexpr char kServoOffsetBKey[] = "servo_b";
constexpr char kServoOffsetCKey[] = "servo_c";

}

PlatformControl::PlatformControl(const BoardPins &pins)
    : pins_(pins),
      servoOffsetA_(kServoOffsetDefault),
      servoOffsetB_(kServoOffsetDefault),
      servoOffsetC_(kServoOffsetDefault),
      backend_(PLATFORM_BACKEND_NONE),
      lastInitResult_{PLATFORM_BACKEND_NONE, false, false, false, false, -1, -1, -1} {}

PlatformInitResult PlatformControl::begin(bool forceDummyBackend) {
  lastInitResult_ = {PLATFORM_BACKEND_NONE, false, false, false, false, -1, -1, -1};
  lastInitResult_.preferencesAvailable = loadServoOffsets();

  if (forceDummyBackend) {
    backend_ = PLATFORM_BACKEND_DUMMY;
    lastInitResult_.backend = backend_;
    detachAllServos();
    return lastInitResult_;
  }

  lastInitResult_.channelA = servoA_.attach(pins_.servoPinA, kServoPulseMinUs, kServoPulseMaxUs);
  lastInitResult_.channelB = servoB_.attach(pins_.servoPinB, kServoPulseMinUs, kServoPulseMaxUs);
  lastInitResult_.channelC = servoC_.attach(pins_.servoPinC, kServoPulseMinUs, kServoPulseMaxUs);
  lastInitResult_.attachSucceededA = lastInitResult_.channelA != INVALID_SERVO;
  lastInitResult_.attachSucceededB = lastInitResult_.channelB != INVALID_SERVO;
  lastInitResult_.attachSucceededC = lastInitResult_.channelC != INVALID_SERVO;

  if (!lastInitResult_.attachSucceededA || !lastInitResult_.attachSucceededB || !lastInitResult_.attachSucceededC) {
    detachAllServos();
    backend_ = PLATFORM_BACKEND_DUMMY;
  } else {
    backend_ = PLATFORM_BACKEND_REAL;
  }

  lastInitResult_.backend = backend_;
  return lastInitResult_;
}

void PlatformControl::movePlatform(float rollDeg, float pitchDeg, float height) {
  if (backend_ != PLATFORM_BACKEND_REAL) {
    return;
  }

  const float roll = rollDeg * kDegToRad;
  const float pitch = -pitchDeg * kDegToRad;  // Negate pitch to match physical Y-axis orientation.
  const float baseAngle[3] = {0.0f, 120.0f * kDegToRad, 240.0f * kDegToRad};
  const float platformPhaseOffset = kPlatformPhaseOffsetDeg * kDegToRad;
  float platformX[3];
  float platformY[3];
  float platformZ[3];
  float angles[3];

  for (int i = 0; i < 3; ++i) {
    const float base = baseAngle[i];
    const float platformAngle = base + platformPhaseOffset;
    const float px = kPlatformRadiusMm * cosf(platformAngle);
    const float py = kPlatformRadiusMm * sinf(platformAngle);
    const float pz = height;

    const float x1 = px * cosf(pitch) + pz * sinf(pitch);
    const float z1 = -px * sinf(pitch) + pz * cosf(pitch);
    const float y1 = py * cosf(roll) - z1 * sinf(roll);
    const float z2 = py * sinf(roll) + z1 * cosf(roll);

    platformX[i] = x1;
    platformY[i] = y1;
    platformZ[i] = z2;
  }

  for (int i = 0; i < 3; ++i) {
    const float base = baseAngle[i];
    const float bx = kBaseRadiusMm * cosf(base);
    const float by = kBaseRadiusMm * sinf(base);
    const float dx = platformX[i] - bx;
    const float dy = platformY[i] - by;
    const float dz = platformZ[i];
    const float dxLocal = dx * cosf(base) + dy * sinf(base);
    const float dyLocal = dz;
    const float distance = sqrtf(dxLocal * dxLocal + dyLocal * dyLocal);
    const float armCosine =
        constrain((kServoArmLengthMm * kServoArmLengthMm + distance * distance -
                   kPassiveLinkLengthMm * kPassiveLinkLengthMm) /
                      (2.0f * kServoArmLengthMm * distance),
                  -1.0f,
                  1.0f);
    const float theta = atan2f(dyLocal, dxLocal) - acosf(armCosine);
    angles[i] = theta * kRadToDeg;
  }

  moveServos(angles[2], angles[0], angles[1]);
}

void PlatformControl::moveServos(float a, float b, float c) {
  if (backend_ != PLATFORM_BACKEND_REAL) {
    return;
  }

  a = constrain(a, kServoMinAngleDeg, kServoMaxAngleDeg);
  b = constrain(b, kServoMinAngleDeg, kServoMaxAngleDeg);
  c = constrain(c, kServoMinAngleDeg, kServoMaxAngleDeg);

  servoA_.write(static_cast<float>(servoOffsetA_) - a);
  servoB_.write(static_cast<float>(servoOffsetB_) - b);
  servoC_.write(static_cast<float>(servoOffsetC_) - c);
}

void PlatformControl::setServoOffsets(int offsetA, int offsetB, int offsetC) {
  servoOffsetA_ = clampOffset(offsetA);
  servoOffsetB_ = clampOffset(offsetB);
  servoOffsetC_ = clampOffset(offsetC);
}

void PlatformControl::resetServoOffsets() {
  setServoOffsets(kServoOffsetDefault, kServoOffsetDefault, kServoOffsetDefault);
}

bool PlatformControl::loadServoOffsets() {
  if (!preferences_.begin(kPreferencesNamespace, true)) {
    resetServoOffsets();
    return false;
  }

  setServoOffsets(preferences_.getInt(kServoOffsetAKey, kServoOffsetDefault),
                  preferences_.getInt(kServoOffsetBKey, kServoOffsetDefault),
                  preferences_.getInt(kServoOffsetCKey, kServoOffsetDefault));
  preferences_.end();
  return true;
}

void PlatformControl::saveServoOffsets() const {
  if (!preferences_.begin(kPreferencesNamespace, false)) {
    return;
  }

  preferences_.putInt(kServoOffsetAKey, servoOffsetA_);
  preferences_.putInt(kServoOffsetBKey, servoOffsetB_);
  preferences_.putInt(kServoOffsetCKey, servoOffsetC_);
  preferences_.end();
}

int PlatformControl::servoOffsetA() const {
  return servoOffsetA_;
}

int PlatformControl::servoOffsetB() const {
  return servoOffsetB_;
}

int PlatformControl::servoOffsetC() const {
  return servoOffsetC_;
}

bool PlatformControl::motionAvailable() const {
  return backend_ == PLATFORM_BACKEND_REAL;
}

bool PlatformControl::dummyBackendActive() const {
  return backend_ == PLATFORM_BACKEND_DUMMY;
}

PlatformInitResult PlatformControl::lastInitResult() const {
  return lastInitResult_;
}

void PlatformControl::detachAllServos() {
  if (servoA_.attached()) {
    servoA_.detach();
  }
  if (servoB_.attached()) {
    servoB_.detach();
  }
  if (servoC_.attached()) {
    servoC_.detach();
  }
}

int PlatformControl::clampOffset(int value) const {
  return constrain(value, kServoOffsetMin, kServoOffsetMax);
}

}
